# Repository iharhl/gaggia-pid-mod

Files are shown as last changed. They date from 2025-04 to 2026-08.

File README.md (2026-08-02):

# Gaggia PID mod

This project adds PID temperature control to my Gaggia Classic
espresso machine. Inspired by similar DIY efforts, I wanted to
challenge myself by designing and implementing the modification
entirely from scratch.

By default, Gaggia uses thermostat-based (on/off) temperature control,
which has noticed deviations from the ideal temperature. A PID controller
offers more precise and consistent temperature regulation compared to the
stock thermostat, which helps improve shot quality.

---

**Update Jul 2026:** I decided to create a custom "carrier" PCB which is more
compact, robust, and makes wiring more organized. Instead of using the same
microcontroller board, I switched from Pi Pico to RP2040-Zero (has the same MCU).
This readme file was updated accordingly. See the new control box below.

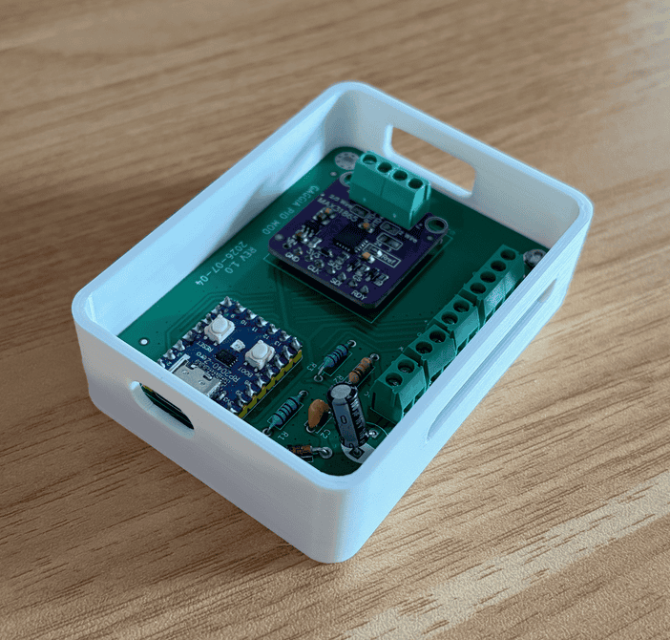
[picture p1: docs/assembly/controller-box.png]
pcb


---

## Table of contents

1. [Hardware](#hardware)
   - [Temperature sensing](#temperature-sensing)
   - [Power switching](#power-switching)
   - [Microcontroller board](#microcontroller-board)
   - [Additional hardware](#additional-hardware)
   - [Bonus: Brew timer](#bonus-brew-timer)
2. [Software](#software)
   - [Temperature measurement](#temperature-measurement)
   - [PID controller](#pid-controller)
   - [Relay control](#relay-control)
   - [Error handler](#error-handler)
   - [Display](#display)
   - [Pump](#pump)
   - [Other](#other)
   - [Helper tools](#helper-tools)
3. [Results](#results)
   - [Calibration](#calibration)
   - [Final assembly (old)](#final-assembly-old-pi-pico-version)
   - [Final assembly (new)](#final-assembly-new-rp2040-zero-version)
   - [Taste Test](#taste-test)
4. [Resources](#resources)

## Hardware

The Gaggia machine regulates temperature using basic thermostat, which
functions as a switch that cuts off power when the water temperature
exceeds its rated threshold – 107°C for brewing. However, this approach
results in a sluggish system response. Once the temperature reaches the
cutoff point, it tends to slowly oscillate around the target, deviating
by several degrees. This rudimentary control method lacks the precision
needed for accurate temperature regulation.

To achieve more precise control, we need to continuously monitor the
water temperature and adjust the power to the heating element dynamically
based on real-time measurements. This allows for smoother and more
accurate temperature control.

To implement such a system, following components are required:

- Temperature sensor
- Power switch
- Microcontroller board

### Temperature sensing

The application requires measuring relatively short-term changes in
temperature over a wide range (~0°C to 200°C) with high accuracy
(better than ±0.5°C).

A common use case that fits these requirements is temperature control
in a water heater, where RTD (Resistance Temperature Detector) sensors
are frequently used. For this purpose, a Pt100 RTD sensor was
selected. It meets the accuracy and range specifications and is readily
available with an M4 adapter suitable for mounting to a boiler.

However, achieving accurate temperature readings from an RTD sensor
requires a precise analog-to-digital converter (ADC) and amplification.
Fortunately, this problem has been effectively solved with the MAX31865
– a user-friendly resistance-to-digital converter optimized for platinum
RTDs like the Pt100. With the MAX31865, you simply connect the sensor,
configure the device, and it provides accurate digital temperature
readings.

Adafruit offers high-quality breakout boards based on the MAX31865
chip, along with comprehensive documentation and example code. The sensor
itself I found on AliExpress with integrated M4 screw and of 3-wire type.
See examples of MAX31865 and RTD sensor below.

<p>
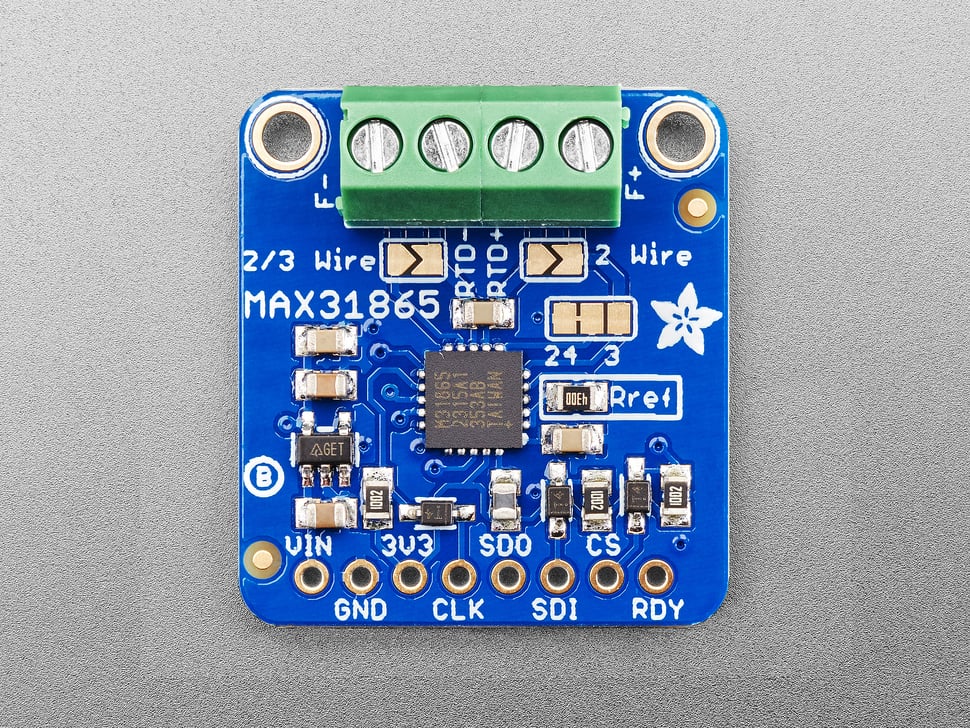
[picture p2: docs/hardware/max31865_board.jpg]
hw_MAX31865

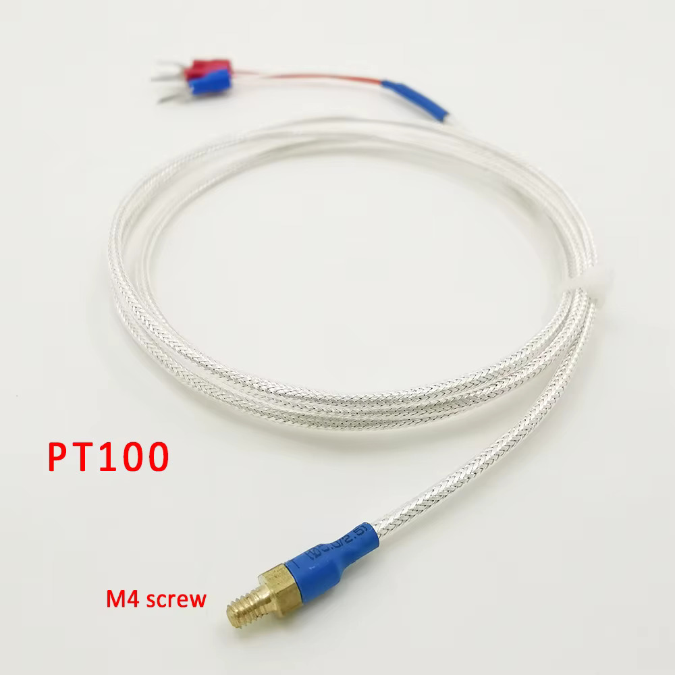
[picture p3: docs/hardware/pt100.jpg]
hw_PT100

</p>

### Power switching

With the thermostat removed, an alternative method is needed to switch
the power on and off. A mechanical relay is the most straightforward
option and probably could suffice.

However, solid-state relays (SSRs) are often preferred in high-power
scenarios for several practical reasons. While both options are capable
of handling the load, SSRs offer significant advantages:

- Silent operation: unlike mechanical relays that produce an audible
"click" during switching, SSRs operate silently.

- Longer lifespan: SSRs have no moving parts, which drastically reduces
mechanical wear and increases operational longevity, particularly under
frequent switching conditions.

- Faster switching: the ability of SSRs to switch much faster than
mechanical relays.

- Reduced electrical noise: SSRs can be zero-crossing triggered, 
minimizing electrical noise and transients during switching.

Given these benefits, I opted for a commonly available 40A-rated SSR.
These are widely used, reliable, and relatively inexpensive, making
them a solid choice for high-power switching applications. According
to the specifications, the control method is listed as zero-crossing.
The SSR model is shown on the image below.

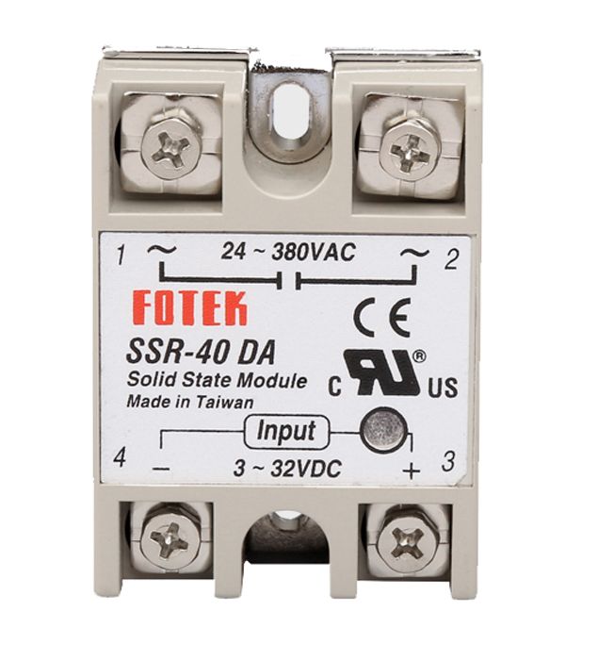
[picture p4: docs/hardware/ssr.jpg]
hw_SSR


### Microcontroller board

There are many microcontrollers that could handle this task, as long as
they provide enough GPIO pins, support both I2C and SPI communication,
and have sufficient memory resources.

I had a Raspberry Pi Pico on hand that I hadn’t worked with before, so
I decided to use it as the microcontroller for this project.

**Update Jul 2026:** for a carrier PCB, I switch the board to RP2040-Zero –
both are supported now.

<p>
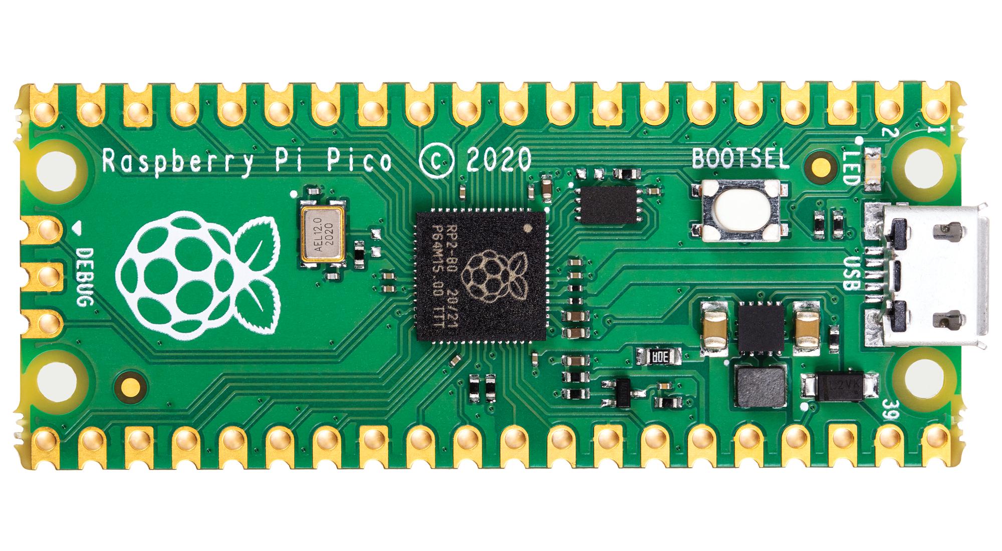
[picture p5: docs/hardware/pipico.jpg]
hw_PICO

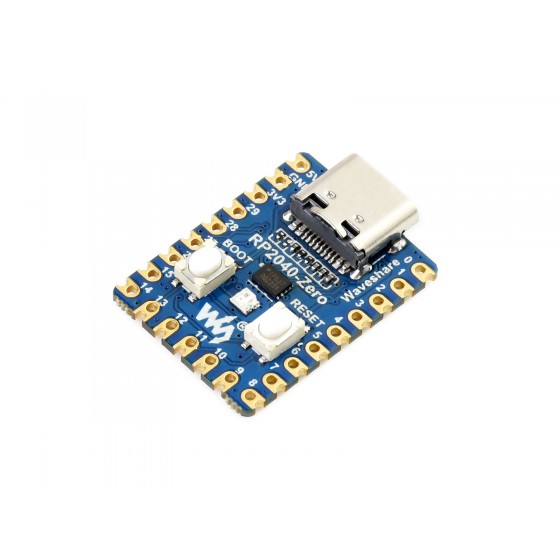
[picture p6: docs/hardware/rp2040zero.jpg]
hw_ZERO

</p>

### Additional hardware

The components mentioned above cover the core functionality, but a few
important elements are still missing.

First, the Raspberry Pi Pico needs a power source. While it can be
powered via USB during development and debugging, this is only a
temporary solution. For a standalone setup, an AC/DC power supply is
required to draw power from the machine itself. I found a small module
on AliExpress that outputs up to 600mA at 5V, which is more than
sufficient for powering the Pico and a few peripherals.

The module turned out to be of poor quality. Its output was quite noisy,
and there were grounding issues. While most components in the system
would tolerate these, the MAX31865 is considerably more sensitive. As a
result, it frequently reported faults during temperature readings.

Fortunately, I had an AC/DC power supply from my broken speakers on hand,
so I used it for this project. Adding a pair of decoupling capacitors to
its output (100µF electrolytic and 0.1µF ceramic) resulted in a very smooth
voltage curve. However, the output measured at ~6V, which is around absolute
maximum rating of the on-board regulator. I used a diode to introduce a
voltage drop. Additionally, the power supply discharged very slowly after
the power was cut off. To address this, I soldered in a low-value bleed
resistor to speed up the discharge. In the end, the Pico is powered via
the VSYS pin with a stable ~5.1V supply.

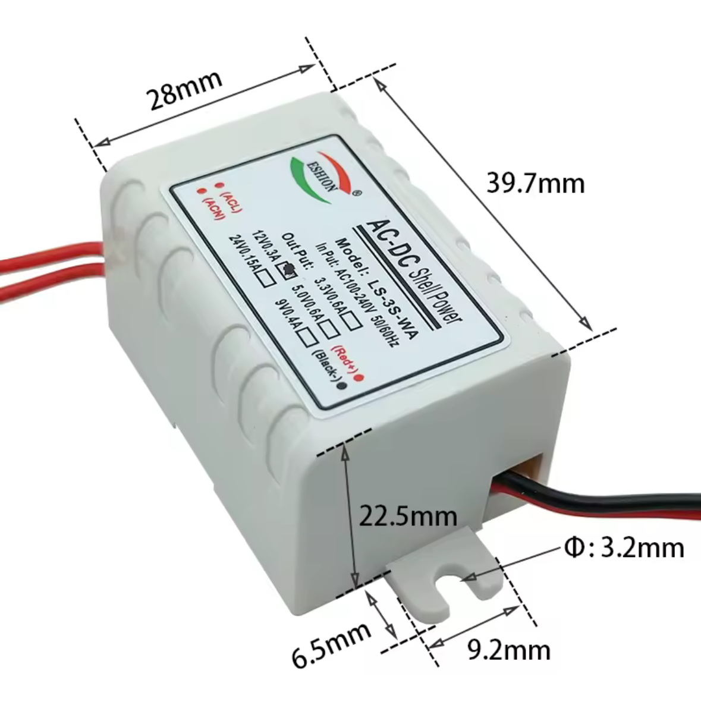
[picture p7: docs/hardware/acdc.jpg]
hw_ACDC


Second, we need a way to monitor the machine's temperature in real
time. A small display would be a practical addition for this purpose,
allowing for quick and convenient observation of temperature readings.
I came across a very nice 1.5" 128×128 grayscale OLED display from
Adafruit, which includes comprehensive documentation.

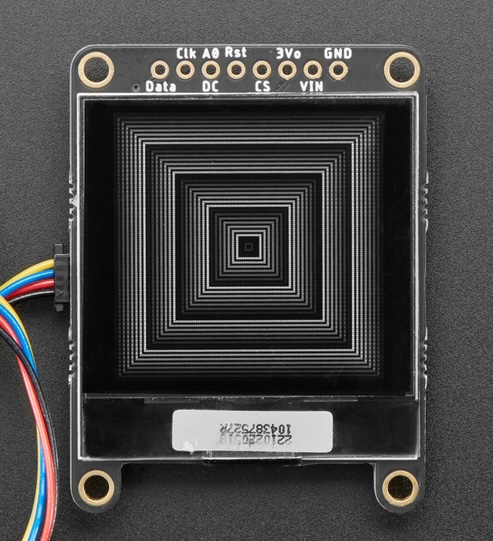
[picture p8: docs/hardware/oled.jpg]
hw_OLED


### Bonus: Brew timer

Regarding the hydraulics upgrade, one of the most popular modifications
is the dimmer mod. This approach controls the pump flow by chopping the
AC supply using a phase-angle dimmer circuit. While it allows for
pressure profiling, it is worth noting that this method can lead to
increased wear on the pump, as this vibration pump is not designed to
operate under such conditions.

A simpler alternative is pump time control. By interrupting power to the
pump, you can implement programmable shot timing – effectively automating
brew durations without modifying flow or pressure directly. All that is
required for this mod is a relay board and some wiring to detect when the
brew button has been pressed.

Since I dragged this project out for too long, I ultimately decided
to skip the relay part of the mod – it would not have made a meaningful
difference for my use case anyway. However, I wired the brew button
to the Pico.

On the EU model of the machine, there is a switch-off board
included. Wires on the left side of the brew switch (in my case, blue and
green ones) are connected to it so that the power-off timer is reset
when brewing. I removed these two wires and shorted them (to make the
board think the brew is on at all time). The available connections can
now be used to detect when the button is pressed.

## Software

Since the Pico board was chosen, the MCU provides plenty of resources to
write a somewhat abstract code :)

To make the implementation easier to write and more readable, I followed
an OOP approach. Each component with a specific purpose is encapsulated
in its own class. For example, each communication protocol (I2C/SPI) is
implemented as a separate class. The drivers for external components,
such as MAX31865 and the OLED display, are also organized into classes
that utilize the I2C or SPI class instances for communication.

Here is a high-level overview of the software:

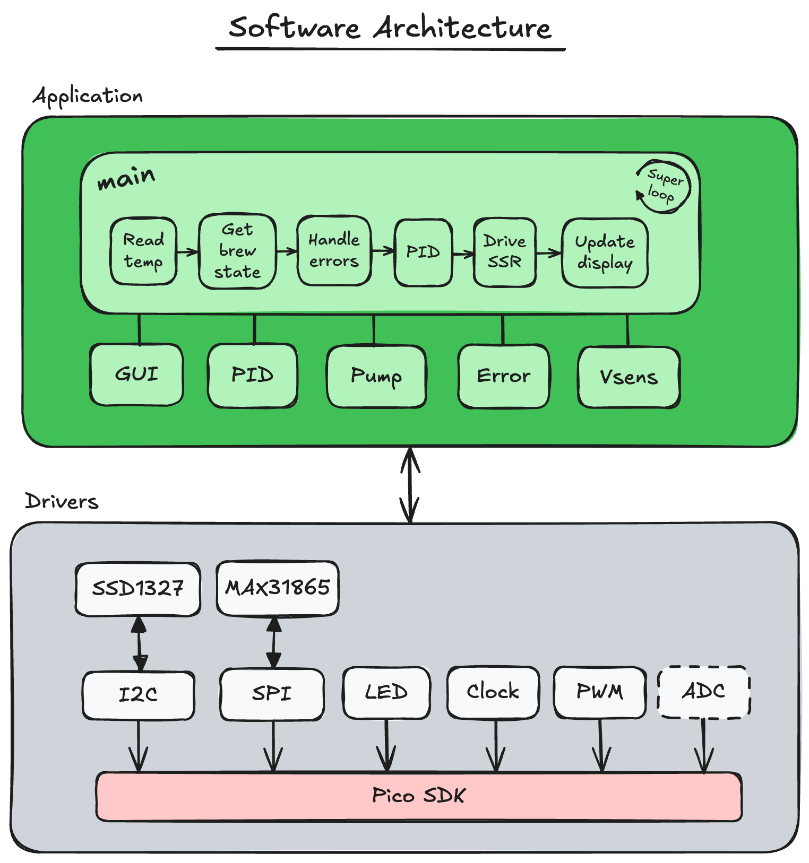
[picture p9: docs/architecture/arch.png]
SW-arch


### Temperature measurement

Temperature measurements are obtained via the MAX31865 chip, which
uses SPI for communication. Hence, the SPI driver class was implemented.
Due to specific timing requirements of the MAX31865, slight modification
were done to the native Pico SDK SPI calls. The details are available in 
the implementation file – [src/spi.cpp](src/spi.cpp). Below are examples of
SPI read and write operations captured with a logic analyzer:

<p>
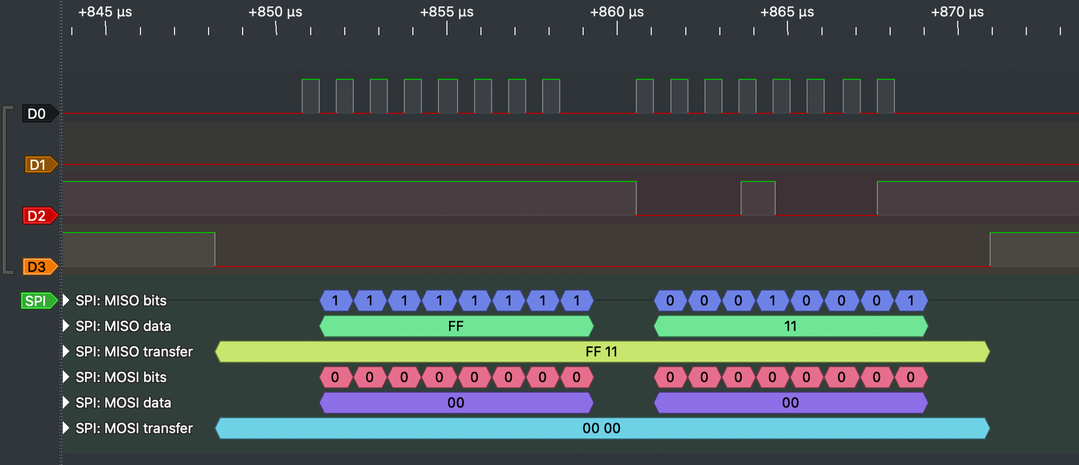
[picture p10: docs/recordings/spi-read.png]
SPI-read

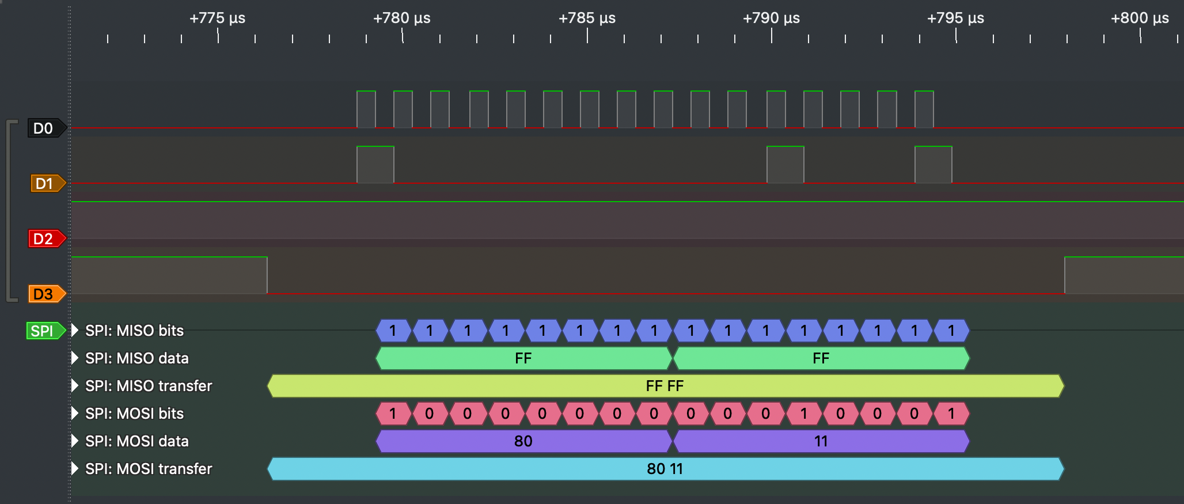
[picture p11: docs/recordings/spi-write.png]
SPI-write

</p>

The MAX31865 driver implements the chip-specific logic
and utilizes the SPI class instance for communication. Details can be
found here – [src/max31865.cpp](src/max31865.cpp)

### PID controller

Not much to explain here – a PID temperature controller logic is
encapsulated within the PID class. The implementation is minimal, only
includes basic P-I-D action, no filtering, and includes integral
anti-windup to prevent the accumulation of integral action (which is 
important in such slow control systems).

The PID compute method takes temperature setpoint and the measurement as
inputs (error is calculated inside), and outputs the PWM percentage (duty
cycle). Implementation can be found here –
[src/pid.cpp](src/pid.cpp)

### Relay control

The SSR is controlled via PWM, hence the logic is put into PWM class.
The small problem here is that the control systems is quite slow
leading to a long PWM period, too long to be controlled using Pico's
dedicated PWM peripherals. Therefore, the PWM logic was implemented
via combination of timer peripheral and GPIO actions. Check details here –
[src/pwm.cpp](src/pwm.cpp)

<small>

> An interesting consideration here is how much power is delivered to the
heating element during each PWM period. Here's what I mean: suppose
the PID controller outputs a 10% duty cycle. Depending on the length
of the PWM period, this 10% can represent different chunks of time –
for example, 0.11 sec.
> 
> In the EU, the AC mains frequency is 50 Hz, meaning each full AC cycle
lasts 20 ms. However, 0.11 sec is not an even multiple of
the AC period (0.11 / 0.02 = 5.5 cycles), so the PWM period slices
through the AC waveform at arbitrary points. As a result, depending on
exactly where in the AC cycle the PWM turns on or off, the average power
delivered can fluctuate between periods.
>
> To achieve more consistent power delivery, it is desirable to align the
PWM period so that it is an integer multiple of the AC cycle period – for
example, setting the PWM period to 2 seconds (100 full AC cycles). This
way, for any given duty cycle, the on-time will always correspond to a
whole number of complete AC periods, rather than cutting through the AC
waveform at arbitrary points. As a result, the average power delivered
becomes more predictable and stable.
>
> Of course, there are some caveats here, and the topic can get quite
technical – including issues like the non-ideal nature of mains
frequency, inrush current when switching at AC peaks, and other
electrical nuances. That said, these details are not critical for this
particular system in my opinion, especially since the SSR I chose
features zero-crossing control. Still, it's an interesting topic to
explore.

</small>

### Error handler

As this mod is not exactly stress-tested, some form of error handler was
logical to implement.

The approach I took was straightforward: during a cycle, the system
checks whether input conditions are met. If a condition fails and the
associated error has a higher priority than previously stored error, the
system stores the new error code. At the end of the loop, the following
actions are taken:

- Disable PWM output if the error is severe enough.

- Display the current error code. If no error is present, reset the
error status and re-enable the PWM.

Possible error codes are summarized in the table below:

| Error Code | Error Context | Description |
|---|---|---|
| P0 | Protection | Watchdog just rebooted the MCU (execution will continue shortly) |
| P1 | | VSYS ADC is not configured correctly |
| P2 | | Over voltage detected on VSYS |
| P3 | | Under voltage detected on VSYS |
| P4 | | Boiler too hot (higher than typical steaming temperature) |
| P5 | | Machine was running for too long |
| C0 | Communication | Error occurred during I2C communication |
| C1 | | SPI device seems to be disconnected |
| S0 | Sensing | MAX31865 reports under/overvoltage |
| S1 | | MAX31865 reports RTD input voltage is too low |
| S2 | | MAX31865 reports reference input voltage is too high |
| S3 | | MAX31865 reports reference input voltage is too low |
| S4 | | MAX31865 reports RTD resistance is lower than the configured low threshold |
| S5 | | MAX31865 reports RTD resistance is higher than the configured high threshold |
| S6 | | Abnormal / not realistic boiler temperature (without MAX31865 reporting faults) |
| HI | User info | Warning to the user that boiler temperature above setpoint (does not disable the PWM) |
| LO | | Warning to the user that boiler temperature below setpoint (does not disable the PWM) |
| OK | | Boiler temperature close to setpoint and no errors detected |

Check the implementation here – [src/error.cpp](src/error.cpp)

### Display

The OLED display uses SSD1327 driver chip with I2C as the default
communication protocol. I chose to structure the display logic in
3 layers:

- The I2C driver class handles communication. The default timings in the
Pico SDK were sufficient, so no modifications were necessary. Check 
here – [src/i2c.cpp](src/i2c.cpp)

- The SSD1327 driver manages the logic for updating the display, such
as filling or clearing the screen, drawing specific regions, and more.
Implementation can be found here – [src/ssd1327.cpp](src/ssd1327.cpp)

- The GUI driver oversees the display layout, including how quickly the
display is updated and how individual numbers or letters correspond to
an actual pixel data. Source file – [src/gui.cpp](src/gui.cpp)

Image below shows the layout of 128x128 display:

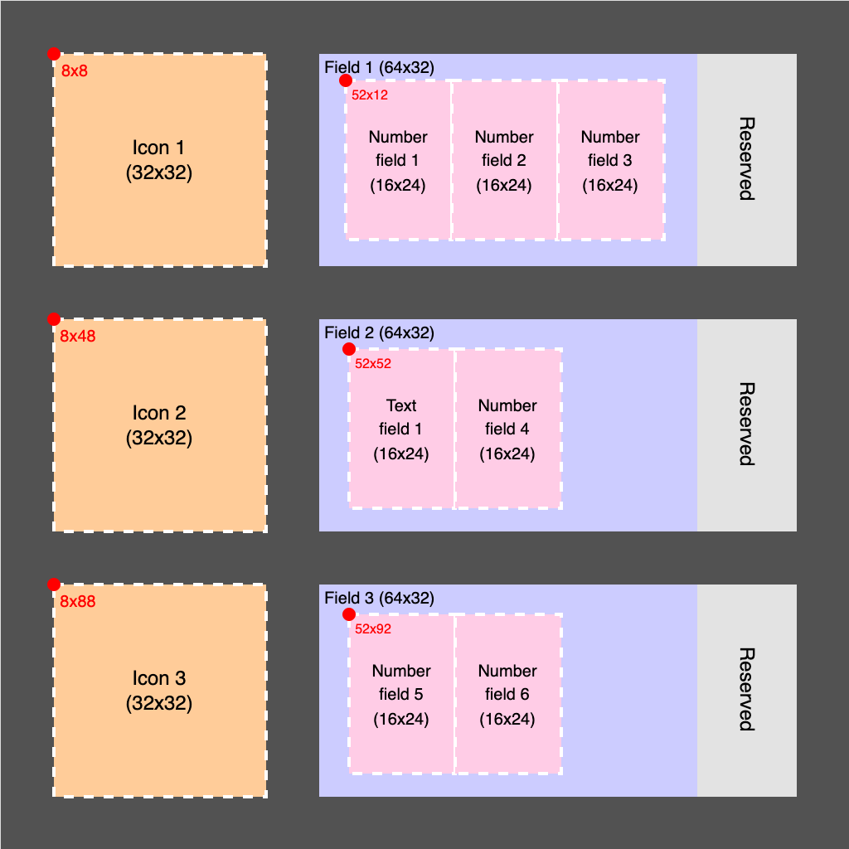
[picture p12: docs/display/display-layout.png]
disp


It is split into three rows. These rows are:

1. Thermometer icon and three digit fields to show the temperature
of the boiler.
2. Status icon and two fields to show the status code. Error codes are 
represented as a letter and a number (except for HI/LO/OK status codes).
3. Cup icon and two digit fields to show the shot timer. When the brew
switch is pressed, the timer starts. After the button is released, the
timer remains visible for 5 seconds before automatically resetting to
zero. The cup icon changes if the brew timer is active.

Images below show examples of what can be displayed.

<p>
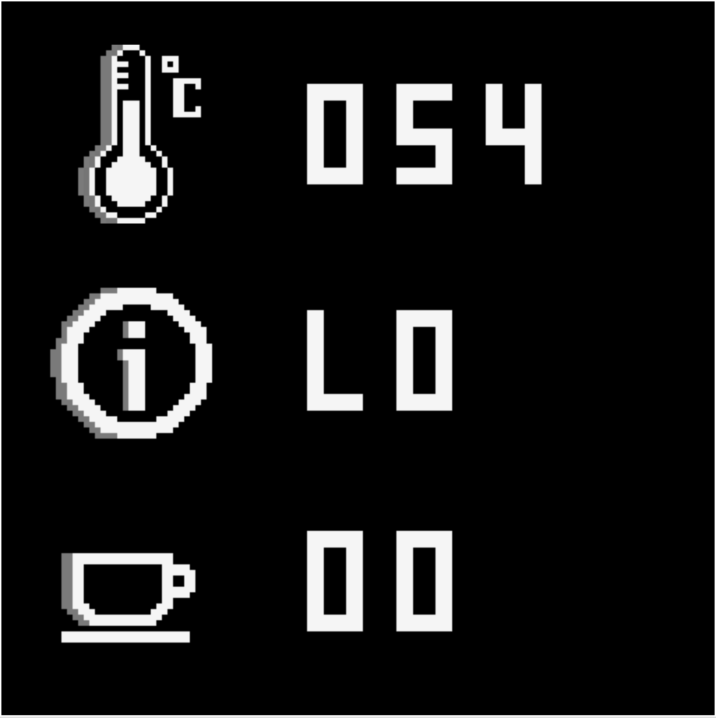
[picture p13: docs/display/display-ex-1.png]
disp-ex1

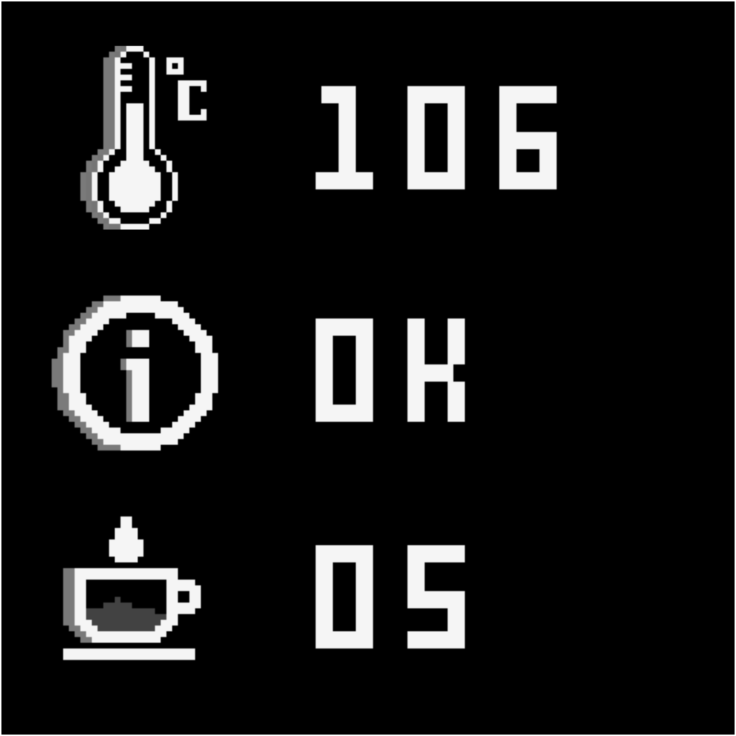
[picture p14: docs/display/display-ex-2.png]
disp-ex2

</p>

<small>

> All the icons, letters, and numbers were drawn by me using an online
> designer for pixel art – Pixilart. The original .pixil files, generated
> png images, etc. are stored in [docs/display/](docs/display)

</small>

### Pump

The pump logic is based on a simple state machine. When the brew button
is pressed, the normally closed (NC) relay remains inactive, allowing
the water to flow. After the programmed time elapses, the relay opens,
cutting the power to the pump. After the brew button is released by the
user, the relay returns to its default closed position. For details, see
– [src/pump.cpp](src/pump.cpp)

This setup enables precise shot timing without the need for manual
tracking of time. While I have not set up the relay part myself, I've
left the code in place.

The part of the code that is used though, is detection of brew button
presses. This enables real-time display of the shot extraction time.

### Other

Source code also includes:

- Clock class provides current uptime of the MCU in ms, sec, and min.
All the methods are static as the class does not need to be instantiated,
it just encapsulates the logic relevant to time. Check
[src/clock.cpp](src/clock.cpp)

- Led class controls the on-board LED. Same as clock, all methods are
static. Check [src/led.cpp](src/led.cpp)

- Vsys monitor class provides the ability to measure the voltage on VSYS line.
As the ADC handling is minimal in the software, I decided to not create a
separate class for it. Check [src/vses.cpp](src/vsens.cpp). **Update Jul 2026:**
custom PCB has a voltage divider, which PR2040-Zero uses to read VDC from
the AC/DC supply, instead of measuring VSYS line itself.

- Watchdog that reboots the MCU if it is not updated in a defined amount
of time. It has no class of its own, direct SDK calls are used.

- For debug and test data recording, custom print functions were
implemented. They communicate data over serial to a connected
computer. Check [src/myprint.h](src/myprint.h)

### Helper tools

To aid the development, I made several scripts which are stored in the
[tools/](tools) folder.

| Script | Description |
|---|---|
| flash.sh | Build and flash the binary on the Pico or PR2040-Zero boards and print its size |
| listen.py | Connect to serial port and record data transmitted from the Pico |
| process-data.py | Parse and plot the temperature data recorded from serial |
| png-to-bytes.py | Convert png image into raw data to be displayed on the OLED |

## Results

### Calibration

To calibrate the PID, I began by recording performance data. The
graphs below show the final results I was able to achieve after some
calibration.

The boiler heat-up is quite smooth, reaching operating temperature in
about 100 seconds. The system seems slightly over damped, requiring some
effort to reach the final few degrees. Once at temperature, it oscillates
with a ±1°C deviation for a short while. Given the system's slow thermal
response, I consider this level of accuracy quite acceptable. By around
the 4-minute mark, the error narrows to about ±0.5°C and continues to
improve over time.

The result of a shot pull test is also shown below. During brewing, the
water temperature drops by almost 3°C. After, it overshoots by about
1.5°C but stabilizes relatively quickly, with full recovery achieved
within a minute.

<p>
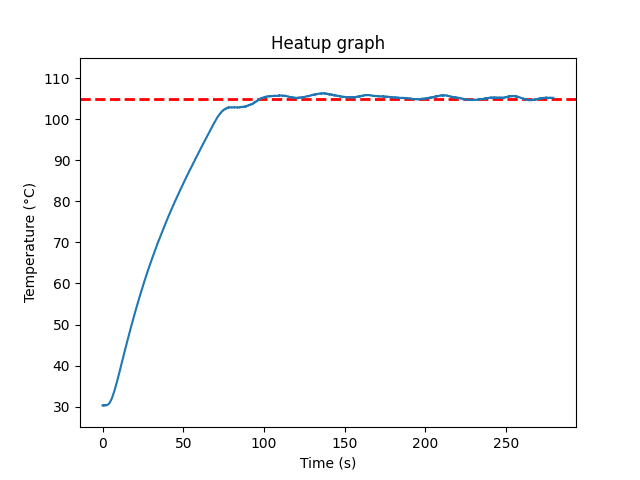
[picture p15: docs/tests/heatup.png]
init_heat

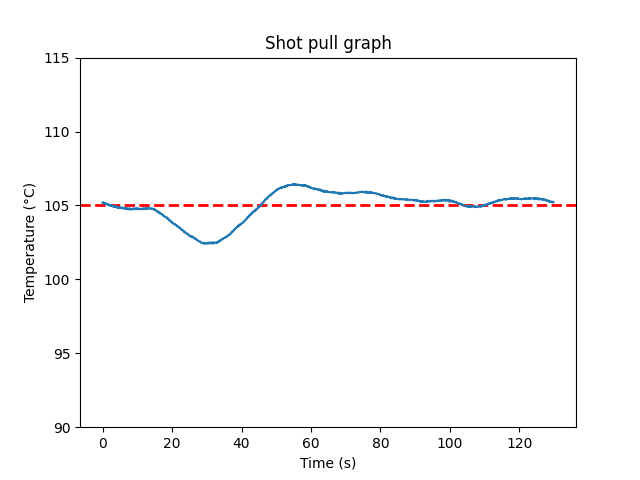
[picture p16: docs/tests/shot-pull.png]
shot_pull

</p>

Additionally, I tested how well my modification works with the stock
steam control. As expected, once the boiler was heated, I reset the
steam switch, and the temperature gradually decreased. After such a
prolonged (passive) cooling, the integral term accumulated significantly,
resulting in an initial temperature undershoot (visible at around the
600-second mark). However, within about one and a half minutes, the
controller compensated and returned the system to the setpoint.

While this is not a realistic usage scenario – doubt anyone would really
wait 10 minutes for the boiler to cool passively (while having the machine
on) – I conducted a more practical test next. After reaching steam
temperature, I manually dropped the temperature by flushing water. This
caused the temperature to fall below the setpoint, but the controller
responded quickly. Two factors contributed to the improved response:
first, the integral term had less time to accumulate error; second, the
steep drop triggered a strong derivative response. In this test, the
system recovered rapidly and stabilized efficiently.

<p>
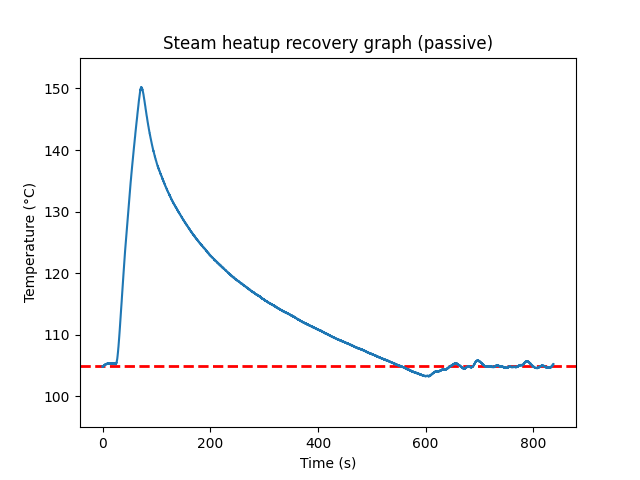
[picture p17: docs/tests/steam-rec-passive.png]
steam_act

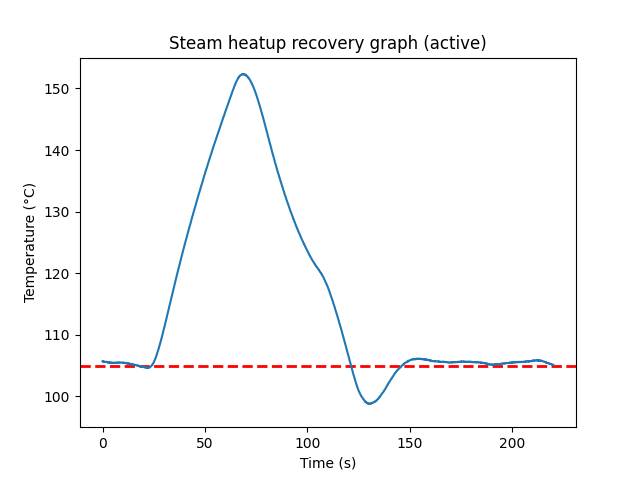
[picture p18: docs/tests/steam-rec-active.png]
steam_pas

</p>

Overall, the controller is stable, and the system's performance is more
than adequate for real-world use – substantially better than the stock
configuration. Although further PID tuning is possible, the current
setup delivers great results.

### Final assembly (old Pi Pico version)

The circuit diagram of the final assembly is shown below. It illustrates
how most of the components were wired together.

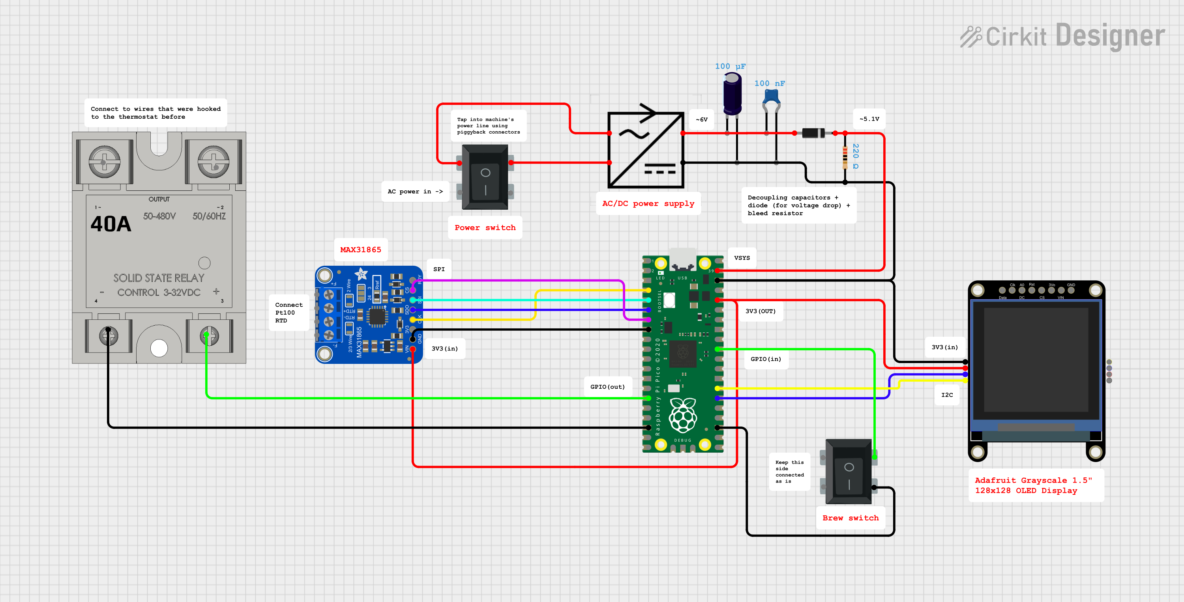
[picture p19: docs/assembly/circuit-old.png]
cir-old


The photos below provide a rough overview of the assembly process. In
the first image, I have highlighted the main modification. Here is a
brief explanation of the numbered tags:

1. **Power Source** – Power is drawn from the machine using piggyback
   connectors, which are active when the main power switch is turned on.
2. **Power Supply Box** – Contains the AC/DC power supply and a small
   piece of protoboard with the necessary components soldered in.
3. **RTD Sensor** – Replaces the machine's original thermostat.
4. **Solid-State Relay (SSR)** – Its AC side is connected to the two
   wires that were previously attached to the brew thermostat.
5. **Brew Switch Wiring** – Two wires are connected to the brew switch
   to detect when it’s pressed. The original disconnected wires are shorted
   to prevent the switch-off board from shutting down the machine.
6. **Control Box** – Houses the Raspberry Pi Pico and the MAX31865.

In the second image, you can see the fully assembled machine. The display
is mounted in a case attached to the side of the machine.

<p>
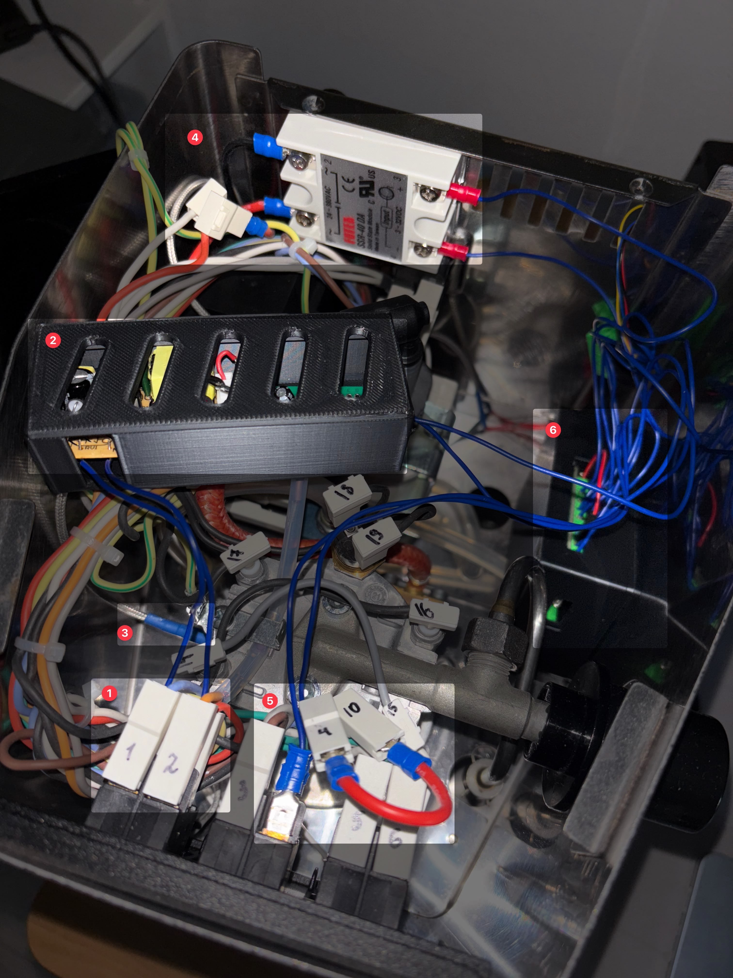
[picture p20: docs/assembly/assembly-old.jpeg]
assem-old

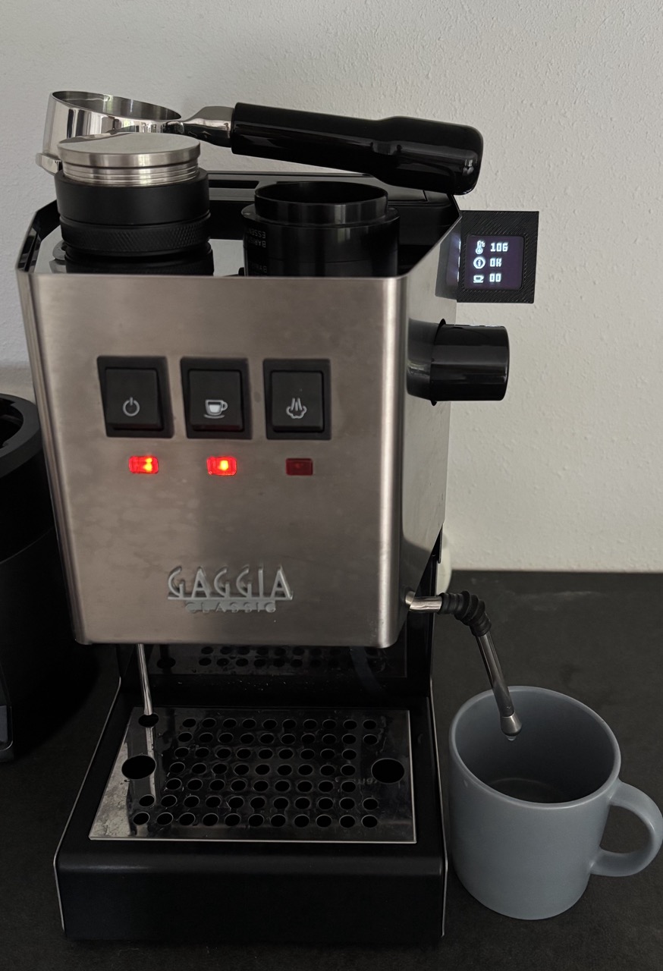
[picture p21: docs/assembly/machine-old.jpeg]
mach-old

</p>

### Final assembly (new RP2040-Zero version)

Updating the assembly in Jul 2026 resulted in a change of a circuit diagram. See
the updated version below. Noticeable differences are:

- The MCU board switched from Pi Pico to RP2040-Zero.
- Voltage divider circuit is no longer on-board – dedicated 22k/10k one is added
  to the custom PCB. Note that it would be better to put it after the capacitors,
  but still works okay as shown.

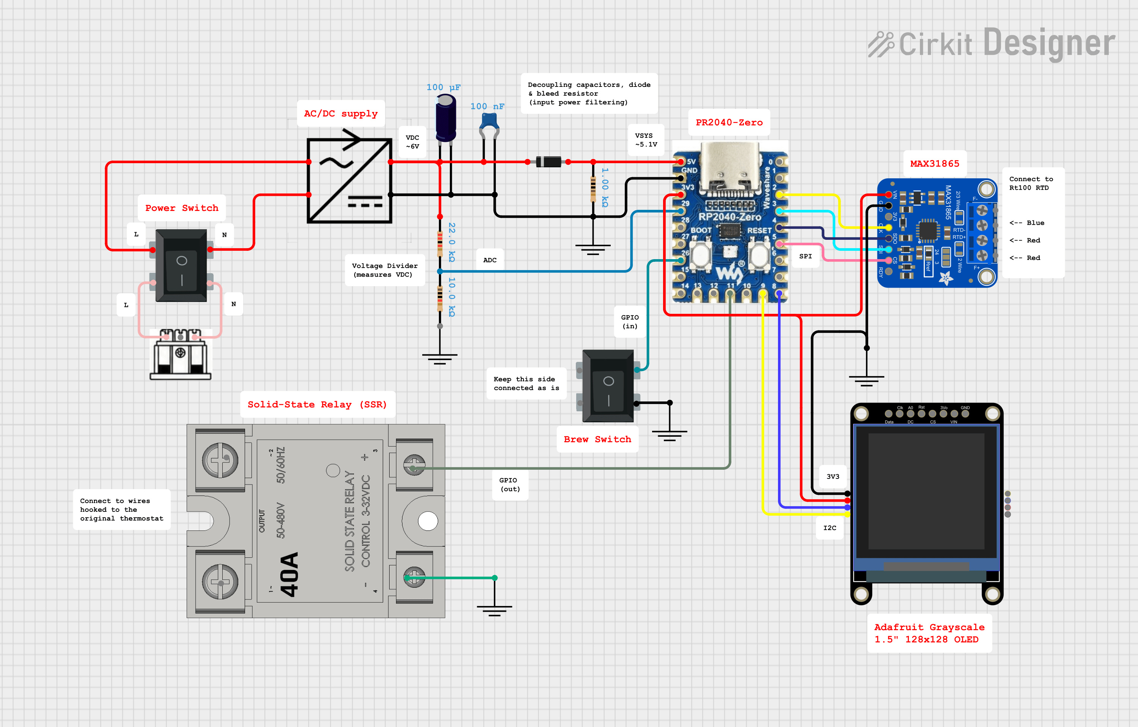
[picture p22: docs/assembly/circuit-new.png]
cir-new


Same as in the previous chapter (old assembly), the photos below show how the new
assembly looks like. In the first image, the main modification are highlighted
with the same number order. The wiring looks way cleaner in the new version.

All the enclosures were updated (for the controller, AC/DC supply and display).
Screen's enclosure is now magnetically attached to the machine's body. I made
hollow standoffs and put few tiny (6x2mm) neodymium magnets there which keep the
screen securely attached to the machine.

<p>
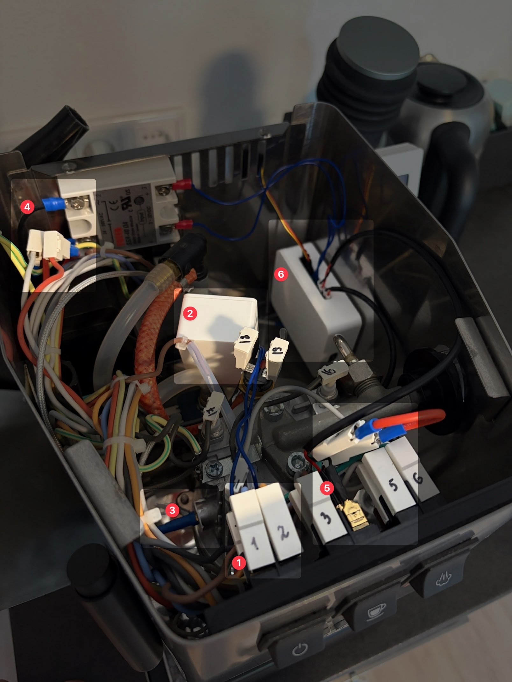
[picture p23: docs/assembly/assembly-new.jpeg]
assem-new

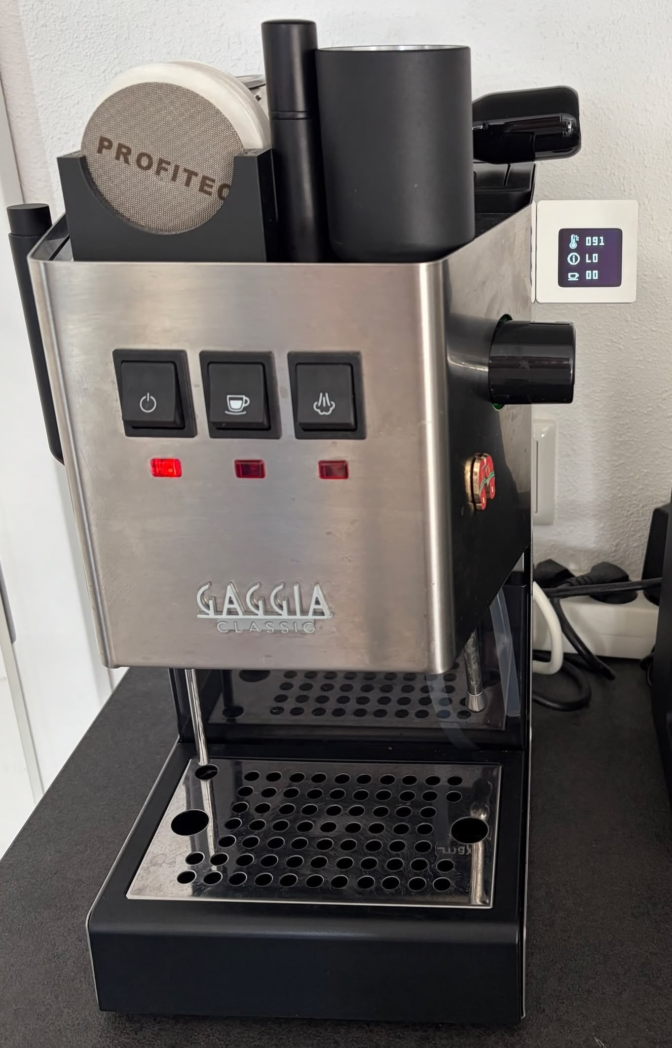
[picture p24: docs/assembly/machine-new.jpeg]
mach-new

</p>

### Taste test

Finally, let's talk about the coffee itself. As a not-so-hardcore coffee
enthusiast, here is my take on the stock machine. Even with specialty beans,
it produced only decent results, definitely better than your average
non-specialty cafe, but still nothing I would drink without milk. The espresso
often leaned too acidic, and not in a pleasant way. Once in a while, I would
even get a hardly drinkable shot (skill issue, gonna admit).

The quality of the shots I got while testing the mod were surprising. I
finally was able to taste those flavor "notes" that coffee influencers always
talk about. The acidity was still present, but now it felt balanced – bright,
not sharp – allowing more complex flavors to emerge.

Even more surprising is that in a test setup and very little effort put
into puck preparation, the espresso tasted substantially better than on
the stock machine.

## Resources

Material on how to approach the mod:
- Gaggiuino project - https://gaggiuino.github.io/#/
- BaristaGadgets kit, specifically this video - https://www.youtube.com/watch?v=gj9qLIDaF9g
- Guide on how Gaggia machine works - https://comoricoffee.com/en/gaggia-classic-pro-circuit-diagram-en/

Example code from Adafruit for drivers development:
- MAX31865:
  - https://github.com/adafruit/Adafruit_MAX31865/tree/master
- SSD1327:
  - https://github.com/adafruit/Adafruit_SSD1327/blob/master/Adafruit_SSD1327.cpp
  - https://github.com/adafruit/Adafruit-GFX-Library/blob/master/Adafruit_GrayOLED.cpp

MAX31865 setup guide:
- https://learn.adafruit.com/adafruit-max31865-rtd-pt100-amplifier/overview

SSD1327 display setup guide:
- https://learn.adafruit.com/adafruit-grayscale-1-5-128x128-oled-display/overview

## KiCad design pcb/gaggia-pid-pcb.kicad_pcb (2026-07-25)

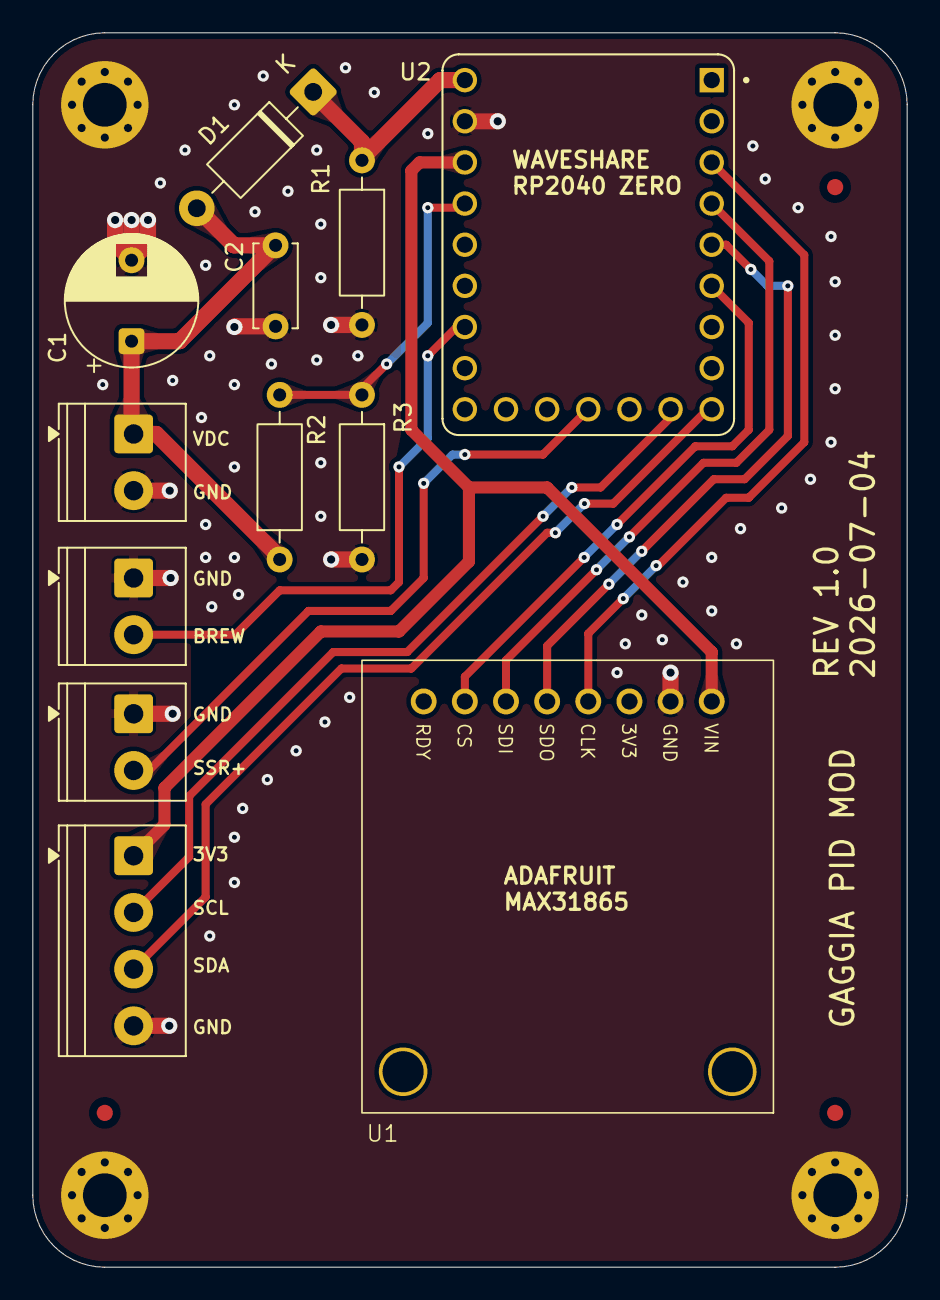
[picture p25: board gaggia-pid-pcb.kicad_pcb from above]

Board: 2 copper layers, 54.0 x 76.2 mm, 19 parts (0 on the bottom side), 13 nets.

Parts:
C1: 100uF; CP_Radial_D8.0mm_P5.00mm
C2: 100nF; C_Disc_D5.0mm_W2.5mm_P5.00mm
D1: 1N47xxA; D_DO-41_SOD81_P10.16mm_Horizontal
FM1, FM2, FM3: Fiducial; Fiducial_1mm_Mask2mm
J1: Conn_01x04; TerminalBlock_Phoenix_PT-1,5-4-3.5-H_1x04_P3.50mm_Horizontal
J2, J3, J4: Conn_01x02; TerminalBlock_Phoenix_PT-1,5-2-3.5-H_1x02_P3.50mm_Horizontal
MH1, MH2, MH3, MH4: M3; MountingHole_2.7mm_M2.5_Pad_Via
R1: 1k; R_Axial_DIN0207_L6.3mm_D2.5mm_P10.16mm_Horizontal
R2: 22k; R_Axial_DIN0207_L6.3mm_D2.5mm_P10.16mm_Horizontal
R3: 10k; R_Axial_DIN0207_L6.3mm_D2.5mm_P10.16mm_Horizontal
U1: Adafruit MAX31865; Adafruit_MAX31865
U2: RP2040-ZERO

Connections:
+3.3V: J1.1, U1.1 (VIN), U2.21 (3V3)
+5V: D1.1 (K), R1.1, U2.23 (5V)
ADC3_VSENS: R2.2, R3.1, U2.20 (GP29)
GND: C1.2, C2.2, J1.4, J2.1, J3.1, J4.2, MH1.1 (1_1), MH2.1 (1_1), MH3.1 (1_1), MH4.1 (1_1), R1.2, R3.2, U1.2 (GND), U2.22 (GND)
GPIO_BREW_SW: J3.2, U2.17 (GP26)
GPIO_SSR: J2.2, U2.12 (GP11)
I2C0_SCL: J1.2, U2.10 (GP9)
I2C0_SDA: J1.3, U2.9 (GP8)
SPI0_CS: U1.7 (CS), U2.6 (GP5)
SPI0_MISO: U1.5 (SDO), U2.5 (GP4)
SPI0_MOSI: U1.6 (SDI), U2.4 (GP3)
SPI0_SCK: U1.4 (CLK), U2.3 (GP2)
VDC: C1.1, C2.1, D1.2 (A), J4.1, R2.1

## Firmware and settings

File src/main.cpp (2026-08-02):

#include "pid.h"
#include "spi.h"
#include "i2c.h"
#include "led.h"
#include "max31865.h"
#include "ssd1327.h"
#include "pwm.h"
#include "gui.h"
#include "pump.h"
#include "error.h"
#include "clock.h"
#include "vsens.h"

#include <cmath>
#include <hardware/watchdog.h>
#include <pico/stdlib.h>
#ifdef DEBUG
#include <string>
#endif //DEBUG


/* Brew control configuration defines */
#define PWM_CYCLE_MS            4000      // pwm cycle length in ms
#define BREW_TEMP_SETPOINT      105
#define BREW_TEMP_HYSTERESIS    2         // for LO/HI status display
#define BREW_PID_KP             9.50
#define BREW_PID_KI             0.45
#define BREW_PID_KD             16.0
/* System protection defines */
#define BOILER_INV_LOW_TEMP     0.0       // invalid temperature reading threshold
#define BOILER_OVH_TEMP         155.0     // boiler overheat temperature
#define BOILER_INV_HIGH_TEMP    190.0     // invalid temperature reading threshold
#define BOILER_MAX_RUNTIME      35        // max boiler runtime with heating on (in min)
#ifdef WAVESHARE_RP2040_ZERO
#define VSYS_MIN_VOLT           3.9       // min VDC voltage allowed (VSYS + 0.8V pre-filter drop)
#define VSYS_MAX_VOLT           6.3       // max VDC voltage allowed
#else
#define VSYS_MIN_VOLT           3.1       // min VSYS voltage allowed
#define VSYS_MAX_VOLT           5.5       // max VSYS voltage allowed
#endif
/* SPI pin configuration defines */
#define SPI_CS_PIN              5
#define SPI_SCK_PIN             2
#define SPI_MOSI_PIN            3
#define SPI_MISO_PIN            4
/* I2C pin configuration defines */
#ifdef WAVESHARE_RP2040_ZERO
#define I2C_SDA_PIN             8
#define I2C_SCL_PIN             9
#else
#define I2C_SDA_PIN             20
#define I2C_SCL_PIN             21
#endif
/* GPIO pin configuration defines */
#define GPIO_SSR_PIN            11
#define GPIO_BREW_SWITCH_PIN    26
/* ADC configuration defines */
#define GPIO_ADC_VDD_PIN        29
#define GPIO_ADC_VDD_CH         3


int main() {
  stdio_init_all();

  // Set up on-board LED
  LED::init();
  LED::turnOn();

#ifdef DEBUG
  sleep_ms(5000);
  printf("[DBG] Board: ");
#ifdef WAVESHARE_RP2040_ZERO
  printf("Waveshare RP2040-Zero\n");
#else //WAVESHARE_RP2040_ZERO
  printf("Raspberry Pi Pico\n");
#endif //WAVESHARE_RP2040_ZERO
#else //DEBUG
  sleep_ms(500);
#endif //DEBUG

  // Set up SSD1327 display and its I2C driver. Set up display manager
  // which handles layout-specific update of the display.
  I2CDevice i2c_device(I2C_SDA_PIN, I2C_SCL_PIN, 400*1000, 0x3D);
  SSD1327 display(&i2c_device, 128, 128);
  DisplayManager gui(&display);

  // Setup voltage monitor on VSYS. On Pico 1 it is connected to GPIO29_ADC3.
  const VsysMonitor vsys_adc(GPIO_ADC_VDD_PIN, GPIO_ADC_VDD_CH);

  // Set up MAX31865 and its SPI driver
  SPIDevice spi_device(SPI_CS_PIN, SPI_SCK_PIN, SPI_MISO_PIN, SPI_MOSI_PIN, 1000*1000);
  MAX31865 temp_sensor(&spi_device, MAX31865_3WIRE, MAX31865_FILT_50HZ);

  // Set up pump class
  Pump pump(GPIO_BREW_SWITCH_PIN);

  // Enable watchdog (should be updated at least 8 times per PWM cycle).
  // If reboot was done -> blink the status code for some time to notify the user.
  if (watchdog_caused_reboot()) {
    gui.blockingStatusAnnouncement(ERROR_CONTEXT_PROT, ERROR_CODE_0);
    gui.resetStatus(true);
    sleep_ms(2000); // can be removed
  }
  watchdog_enable(PWM_CYCLE_MS / 8, false);

  // Set up temperature PID controller (output is pwm duty cycle)
  PIDController pid(BREW_PID_KP, BREW_PID_KI, BREW_PID_KD);
  pid.enableAntiWindup(-40.0, 75.0);

  // Set up PWM signal to the solid-state relay (SSR)
  PWMDriver pwm(GPIO_SSR_PIN, PWM_CYCLE_MS);

  // Setup error handler
  ErrorHandler error_handler(&pwm, &gui);

  while(true) {

    // Get temperature reading from MAX31865
    float temp = temp_sensor.readTemperature();

    // Check if MAX31865 reports faults in temp sensing
    const uint8_t fault_code = temp_sensor.readFault();
    error_handler.verify(fault_code == 0xFF, ERROR_CONTEXT_TEMPSENS, fault_code);
    error_handler.verify(temp > BOILER_INV_LOW_TEMP and temp < BOILER_INV_HIGH_TEMP,
      ERROR_CONTEXT_TEMPSENS, ERROR_CODE_6);

    // Handle faults in the temperature reading
    if (fault_code != 0xFF or temp <= BOILER_INV_LOW_TEMP or temp >= BOILER_INV_HIGH_TEMP) {
      temp = 0.0;
      temp_sensor.clearFault();
    } else {
      // Check if temperature is not too low.
      // Do it only if no fault report otherwise it's set to 0 anyway.
      error_handler.verify(temp > BREW_TEMP_SETPOINT - BREW_TEMP_HYSTERESIS,
        ERROR_CONTEXT_TEMPLO, ERROR_CODE_0);
    }

    // Check if temperature is not too high
    error_handler.verify(temp < BREW_TEMP_SETPOINT + BREW_TEMP_HYSTERESIS,
      ERROR_CONTEXT_TEMPHI, ERROR_CODE_I);

    // Check for errors in SPI and I2C communication
    error_handler.verify(spi_device.isConnected(), ERROR_CONTEXT_COMM, ERROR_CODE_1);
    error_handler.verify(i2c_device.checkErrors(), ERROR_CONTEXT_COMM, ERROR_CODE_0);

    // Update pump state based on the brew switch
    const uint8_t brewtime = pump.updateState();

    // Check for system protection faults
    const float vsys = vsys_adc.readAvg(4);
    error_handler.verify(vsys > 0.0, ERROR_CONTEXT_PROT, ERROR_CODE_1);
    error_handler.verify(vsys <= VSYS_MAX_VOLT, ERROR_CONTEXT_PROT, ERROR_CODE_2);
    error_handler.verify(vsys >= VSYS_MIN_VOLT, ERROR_CONTEXT_PROT, ERROR_CODE_3);
    error_handler.verify(temp < BOILER_OVH_TEMP, ERROR_CONTEXT_PROT, ERROR_CODE_4);
    error_handler.verify(Clock::now_min() <= BOILER_MAX_RUNTIME, ERROR_CONTEXT_PROT, ERROR_CODE_5);

    // Display error if present and disable PWM if needed
    error_handler.act();

    // Compute PWM duty cycle
    const float pwm_duty_cycle = pid.compute(BREW_TEMP_SETPOINT, temp);

    // Drive the SSR (based on the PID output)
    pwm.drivePin(pwm_duty_cycle);

    // Update displayed temperature and brew time
    gui.updateTemperature(static_cast<uint8_t>(roundf(temp)));
    gui.updateShotTime(brewtime);

#ifdef DEBUG
    static unsigned dbg_ticks = 0;
    if (++dbg_ticks % 10 == 0) {
      auto [context, code] = error_handler.get();
      printf("[DBG] T=%3.0fC  PID=%5.1f%%  Vsys=%.2fV  Brew=%us  Err=%d|%d\n",
             temp, pwm_duty_cycle, vsys, brewtime, context, code);
    }
#endif //DEBUG

    // Update watchdog
    watchdog_update();

    // Sleep to make a whole loop execute once in ~100ms (can be removed)
    sleep_ms(23);
  }
}

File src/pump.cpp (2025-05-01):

#include "pump.h"
#include "clock.h"

#include <hardware/gpio.h>
#include <pico/time.h>


Pump::Pump(const uint8_t brewpin, const uint8_t relaypin) :
            m_brewpin(brewpin),
            m_relaypin(relaypin),
            m_autotimer(true) {
    // Set up input brew switch pin
    gpio_init(m_brewpin);
    gpio_set_dir(m_brewpin, GPIO_IN);
    gpio_pull_up(m_brewpin);
    // Set up output pump relay pin
    gpio_init(m_relaypin);
    gpio_set_dir(m_relaypin, GPIO_OUT);
    gpio_put(m_relaypin, false); // NC by default
}

Pump::Pump(const uint8_t brewpin) :
            m_brewpin(brewpin),
            m_relaypin(0), // assign to GP0 which is not used
            m_autotimer(false) {
    // Set up input brew switch pin
    gpio_init(m_brewpin);
    gpio_set_dir(m_brewpin, GPIO_IN);
    gpio_pull_up(m_brewpin);
}

uint8_t Pump::updateState() {
    const bool brew_switch_pressed = !gpio_get(m_brewpin);
    // State machine
    switch (m_state) {
        case STATE_IDLE:
            if (brew_switch_pressed) {
                m_starttime = Clock::now_sec();
                m_state = STATE_BREWING;
                // If auto timer enabled -> keep relay closed
                if (m_autotimer)
                    gpio_put(m_relaypin, false);
            }
            m_brewtime = 0;
            break;
        case STATE_BREWING:
            if (!brew_switch_pressed) {
                m_state = STATE_IDLE;
                break;
            }
            // Get the time since the brew button was pressed
            m_brewtime = Clock::now_sec() - m_starttime;
            // If auto shot time control enabled -> open the relay
            // until the brew switch is reset
            if (Clock::now_sec() >= m_starttime + brewtime and m_autotimer) {
                gpio_put(m_relaypin, true);
                m_state = STATE_WAITFORSWITCHOFF;
            }
            break;
        case STATE_WAITFORSWITCHOFF:
            // After brewing with auto timer, return to idle only if brew
            // switch was switched off by the user
            if (!brew_switch_pressed) {
                gpio_put(m_relaypin, false); // put relay back to closed
                m_state = STATE_IDLE;
            }
            break;
    }
    return m_brewtime;
}

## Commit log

2024-10-13 Setup project and added pid class
2024-12-26 Added MAX31865 driver
2024-12-26 Added spi driver class
2024-12-28 Added led class and fault detection
2024-12-31 Corrected spi driver + added docs dir
    [main.cpp, max31865.cpp, spi.cpp]
2025-01-01 Separated the ssr latch drive logic into pwm driver + moved time related methods into timer class
2025-01-02 Updated pwm pin drive action + pid dT time obtainment
2025-01-04 Added i2c driver + minor fixes around the code
    [i2c.cpp, png-to-bytes.py, spi.cpp]
2025-01-04 Added ssd1327 display driver
2025-01-05 Fixed bug with display init
    [ssd1327.cpp]
2025-01-05 Fixed image of number 4
    [display_manager.h, ssd1327.cpp]
2025-01-07 Created error handler class + added files to docs
    [display_manager.h, main.cpp]
2025-01-08 Updates in error handler and display manager + minor renames/cosmetic changes
    [display_manager.h, error.cpp, main.cpp]
2025-01-08 Updates in error handling/displaying
    [error.cpp, i2c.cpp, main.cpp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]
2025-01-09 Simplified status/error reporting + added some docs
    [display_manager.h, error.cpp, main.cpp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]
2025-01-11 Changes: 1) Changed board to non-W version, 2) Added pump control logic, 3) Removed rough temp calc as not consistent for diff sensors, 4) Few other minor fixes
    [i2c.cpp, led.cpp, main.cpp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]
2025-04-27 Major code refactoring, bugfixes and documentation changes after HIL testing
    [led.cpp, listen.py, main.cpp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]
2025-04-28 Further refinements and bugfixes based on HIL testing
    [log-steam-wait-quick-dump-wait.txt, log-water-dump.txt]
2025-05-01 Added brew time display functionality
    [log-steam-wait-quick-dump-wait.txt, log-water-dump.txt]
2025-05-01 Fixed all warning, fixed some comments, etc.
    [log-steam-wait-quick-dump-wait.txt, log-water-dump.txt]
2025-05-01 Switched from vector to malloc/calloc to reduce binary size
2025-05-02 Fixed led bugs
2025-05-02 Improved error reporting + polishing the code
    [error.cpp, gui.h, main.cpp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]
2025-05-02 Changed the way how comm errors are obtained (esp SPI); update brewing icon (changes on brew); few minor corrections
    [gui.h, i2c.cpp, main.cpp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]
2025-05-02 Updated display documentation + one bugfix in update cut icon
2025-05-04 Bugfixed/polishing after another round of testing
    [i2c.cpp, main.cpp, pwm.cpp]
2025-05-06 Polishing up code + new tests + new section in readme
    [log-steam-wait-quick-dump-wait.txt, log-water-dump.txt]
2025-05-07 Changes - 1) more error checks including Vsys monitoring, overheating and max runtime; 2) added watchdog; 3) small ssd1327 driver and gui handling improvements; 4) other code polishing
    [gui.h, i2c.cpp, main.cpp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]
2025-05-09 Final improvements and test results after some more calibration. Updated readme.
2025-05-18 Updated final assembly in the readme and added the pictures
2026-07-03 Adding support for Waveshare RP2040 Zero board and improving fault handling
2026-07-04 Added PCB files
    [gaggia-pid-pcb.kicad_pcb, gaggia-pid-pcb.kicad_sch]
2026-07-25 Updated Vsens for PR2040-zero board
    [gaggia-pid-pcb.kicad_pcb, gaggia-pid-pcb.kicad_sch]
2026-07-25 Fixes for comp with PR2040-zero board
    [i2c.cpp, main.cpp, spi.cpp]
2026-08-02 Final cleanup for PR2040-zero board (tested release build)
